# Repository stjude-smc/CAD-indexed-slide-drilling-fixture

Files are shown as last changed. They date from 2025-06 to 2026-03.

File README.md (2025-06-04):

# Indexed Slide Drilling Fixture for Quartz Microfluidic Slides

## Motivation

Drilling precise, evenly spaced holes in quartz slides for microfluidic applications is challenging due to the risk of slide flexing, misalignment, and surface damage. Commercial solutions are limited and often lack the flexibility for custom layouts.

**Benefits of this custom-made indexed slide drilling fixture:**

* Rigid, reproducible slide positioning using three reference protrusions and two spring-loaded plungers
* Indexed gear rack mechanism with external spring-loaded plunger enables accurate, repeatable linear movement between hole positions
* Water-filled slide pocket for cooling and debris reduction during drilling
* Cutout beneath the imaging region prevents scratching of the slide surface
* Parametric CAD design allows rapid adjustment of hole pitch and number of fluidic channels for custom microfluidic layouts
* Can be fabricated quickly from stacked, laser-cut acrylic sheets and standard hardware

## Folder Structure

- **cad/** → CAD models
  - **parts/commercial/** → Purchased parts: 3D models, drawings, datasheets, etc.
  - **asm/** → CAD assemblies

- **bom/** → Bill of materials
  - `bom.xlsx` → List of all parts and materials

- **mfg/** → Manufacturing files
  - **3dp/** → 3D printing models (`.STL`, `.preform`, `.3mf`, `.gcode`, ...)
  - **laser/** → Laser cutting files (`.DXF`, `.SVG`, `.PDF`, `.las`)

- **docs/** → Drawings, datasheets, and assembly guides
  - **dwg/** → Drawings for parts and assemblies (`.PDF`)

- **imgs/** → Images for `README.md`

## Manufacturing

The indexed slide drilling fixture can be fabricated using two alternative methods, depending on available equipment and desired material properties:

### Option A: Laser-Cut Acrylic Assembly

1. **Material:** Acrylic glass sheets (thicknesses: 1/16", 3/32", 7/32", and 1/4")
2. **Equipment:** Universal Laser VLS2.30 (or equivalent laser cutter)
3. **Process:**
   - Use the provided `.PDF` or `.SVG` files (see `mfg/laser/`) to laser cut each layer of the fixture.
   - Align and fuse layers together with dichloromethane for a strong, seamless bond.
   - Install spring-loaded plungers before fusing the top layer.

### Option B: 3D Printed Assembly

1. **Material:** Tough 2000 Resin (Formlabs) or equivalent
2. **Equipment:** Formlabs Form 4 (or equivalent SLA 3D printer)
3. **Process:**
   - Use the provided `.STL` files (see `mfg/3dp/`) to print each fixture component.
   - Post-process printed parts as recommended by the resin manufacturer (wash, cure, etc.).
   - Assemble the fixture by gluing parts together with cyanoacrylate (superglue).
   - Install spring-loaded plungers before fusing the top layer.

**Note:**  
Both manufacturing approaches produce a robust fixture suitable for repeated use. The parametric CAD design can be easily adapted for either method to accommodate different slide formats, hole patterns, or channel pitches.

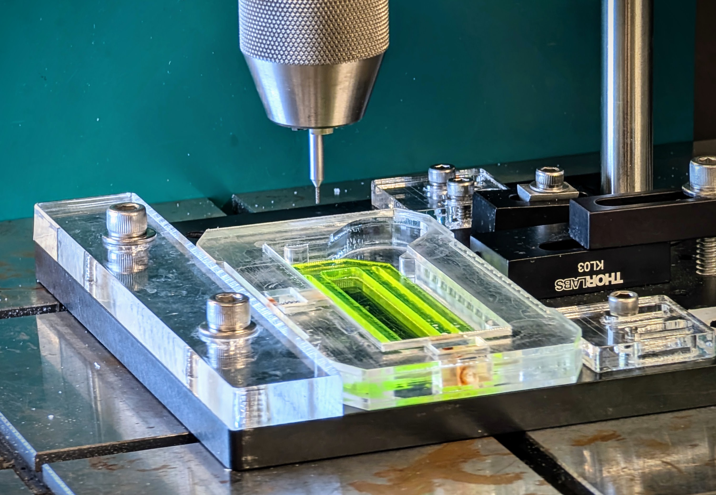
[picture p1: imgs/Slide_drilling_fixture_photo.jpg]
preview


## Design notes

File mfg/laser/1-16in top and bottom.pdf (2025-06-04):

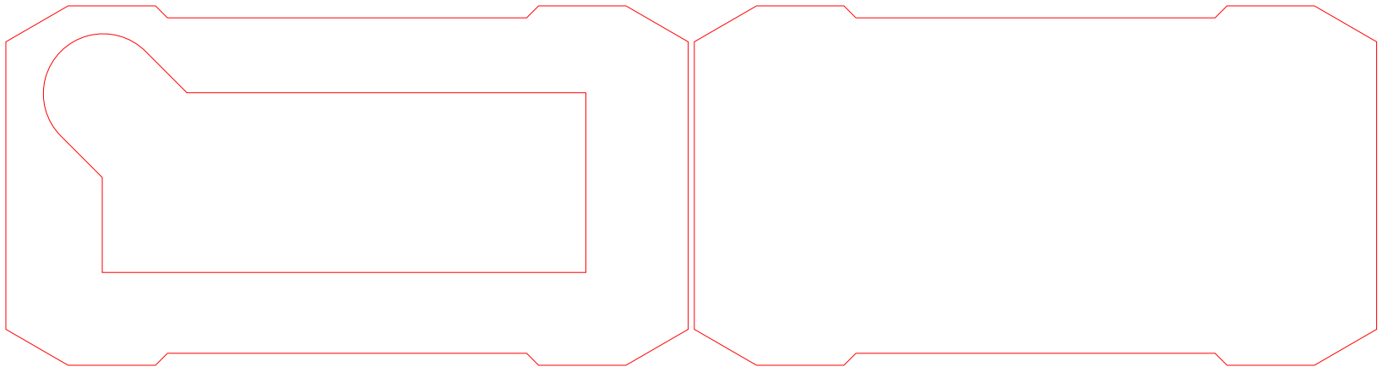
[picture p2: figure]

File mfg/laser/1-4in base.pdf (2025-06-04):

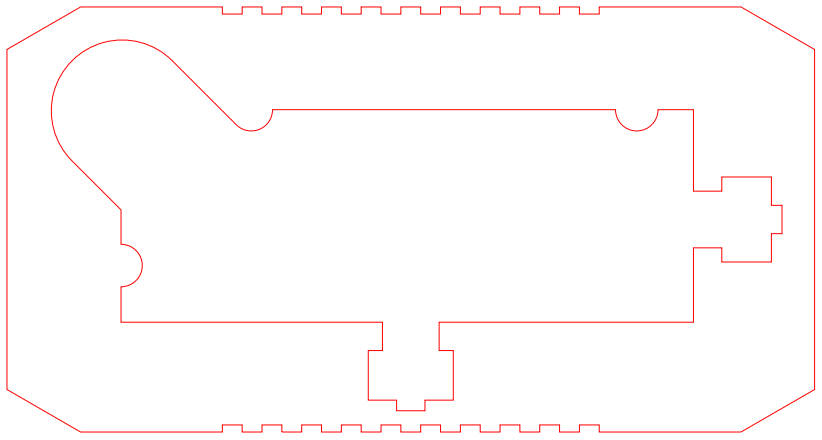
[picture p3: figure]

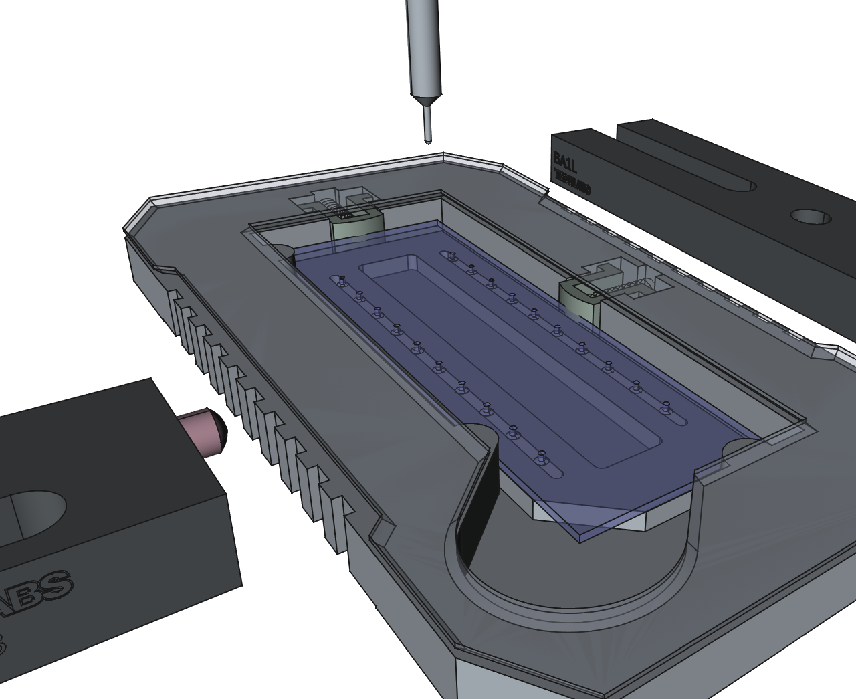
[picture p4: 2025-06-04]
imgs/Slide_drilling_fixture_02.png

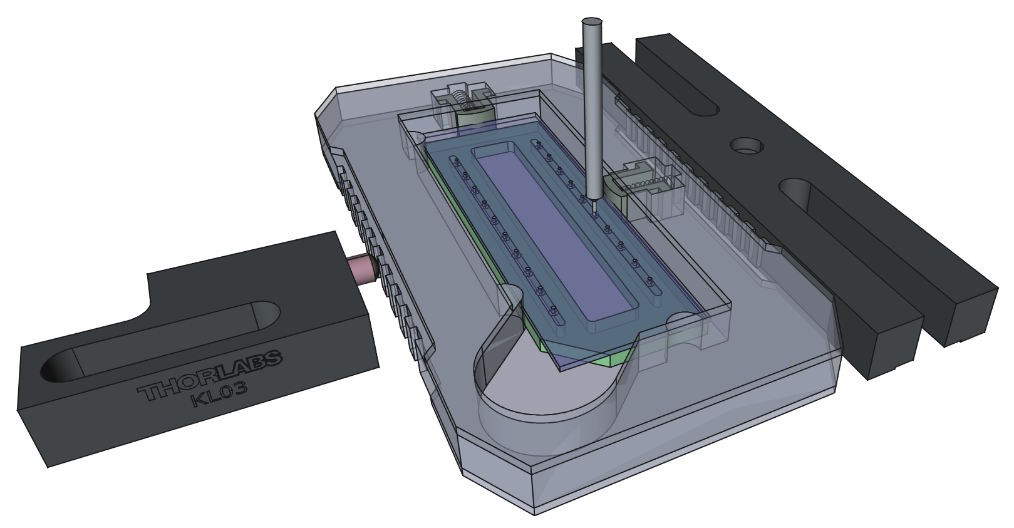
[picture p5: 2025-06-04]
imgs/Slide_drilling_fixture_01.png

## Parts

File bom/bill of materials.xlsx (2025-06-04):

Bill of materials
pTIRF indexed slide drilling fixture v1.0.0
Commercial materials
# | Name | Vendor | Catalog # | Asm qty | Price | Pkg qty | Mult. | Cost | Description
Parts
1 | Compression springs | McMaster | 9435K22 (https://www.mcmaster.com/9435K22/) | 2 | $5.76 | 5 | 0.40 | $2.30 | 302 Stainless Steel Compression Springs 0.75" Long, 0.18" OD, 0.148" ID
2 | Guide | Thorlabs | BA1L (https://www.thorlabs.com/thorproduct.cfm?partnumber=BA1L) | 1 | $14.53 | 1 | 1.00 | $14.53 | BA1L - Mounting Base, 1" x 4.5" x 3/8"
3 | Kinematic positioner | Thorlabs | KL03 (https://www.thorlabs.com/thorproduct.cfm?partnumber=KL03) | 1 | $7.76 | 1 | 1.00 | $7.76 | Spring-Loaded Plunger, 0.85" (21.6 mm) Long Slot
4 | Aluminum breadboard | Thorlabs | MSB6 (https://www.thorlabs.com/thorproduct.cfm?partnumber=MSB6) | 1 | $8.76 | 2 | 0.50 | $4.38 | 6" x 6" x 3/8" Mini-Series Aluminum Breadboard, 8-32 and 1/4"-20 Taps
Raw materials
1 | 1/16" (1.6mm) acrylic glass | McMaster | 8560K178 (https://www.mcmaster.com/8560K178/) | 1 | $3.44 | 1 | 1.00 | $3.44 | 6" x 12" x 1/16" cast acrylic sheet
2 | 3/32" (2.4mm) acrylic glass | McMaster | 8560K188 (https://www.mcmaster.com/8560K188/) | 1 | $3.65 | 1 | 1.00 | $3.65 | 6" x 12" x 3/32" cast acrylic sheet
3 | 7/32" (5.6mm) acrylic glass | McMaster | 8560K179 (https://www.mcmaster.com/8560K179/) | 1 | $9.92 | 1 | 1.00 | $9.92 | 6" x 12" x 7/32" cast acrylic sheet
4 | 1/4" (6.4mm) acrylic glass | McMaster | 8560K359 (https://www.mcmaster.com/8560K359/) | 1 | $13.96 | 1 | 1.00 | $13.96 | 6" x 12" x 1/4" cast acrylic sheet
5 | Tough 2000 resin | Formlabs | RS-C2-TO20-11 (https://formlabs.com/store/materials/tough-2000-resin) | 50 | $149 | 1000 | 0.05 | $7.45 | Tough 2000 Resin (Form 4) 1 L
 |  |  |  |  |  |  | Total | $67.39
Custom parts
# | Name | Qty | Material
Laser cut parts (Universal laser VLS2.30) |  |  |  |  | NOTE
1 | Slide drilling fixture top | 1 | 1/16" acrylic |  | The slide drilling fixture can be either
2 | Slide drilling fixture bottom | 1 | 1/16" acrylic |  | a) laser cut and fused with dichloromethane, or
3 | Slide drilling fixture pedestal | 1 | 3/32" acrylic |  | b) 3D printed and glued with superglue
4 | Slide drilling fixture plunger | 2 | 7/32" acrylic
5 | Slide drilling fixture base | 1 | 1/4" acrylic
3D printed parts (Formlabs Form 4)
1 | Slide drilling fixture base | 1 | Tough 2000 resin
2 | Slide drilling fixture top | 1 | Tough 2000 resin
3 | Slide drilling plunger | 2 | Tough 2000 resin

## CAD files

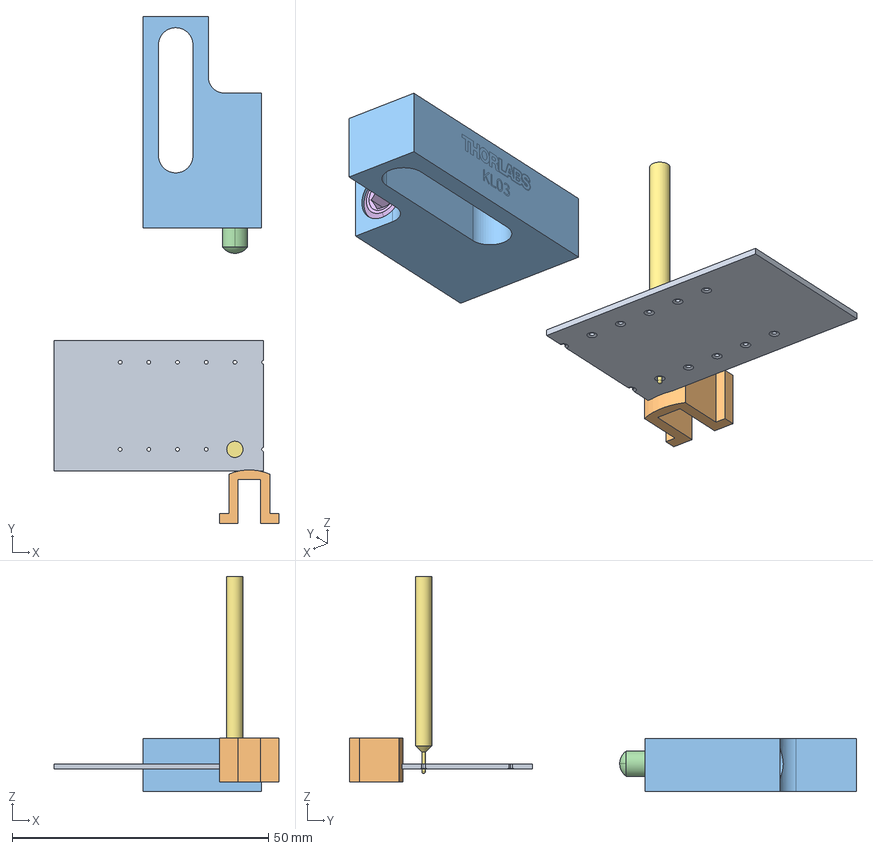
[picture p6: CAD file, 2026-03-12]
cad/asm/indexed slide drilling fixture.FCStd
43.9 x 99.0 x 42.0 mm
QuartzSlide
Plunger
KL03_Step
KL03_Step001
KL03_Step002
KL03_Step003
0.03in Drilling bit

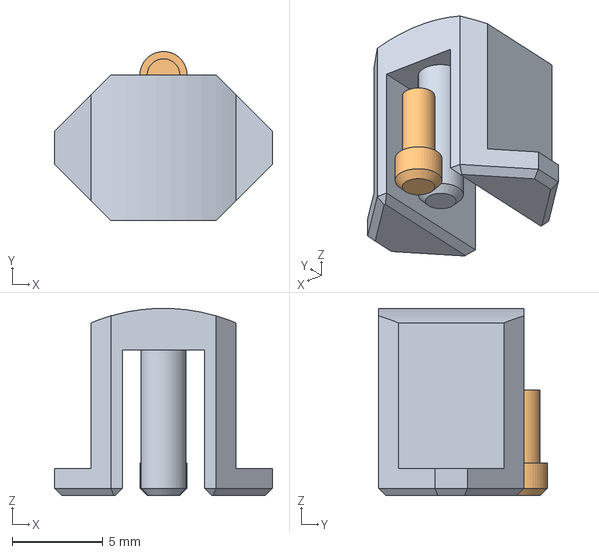
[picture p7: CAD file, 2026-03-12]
cad/parts/alternative plunger.FCStd
12.0 x 9.30 x 10.3 mm
plunger
pin

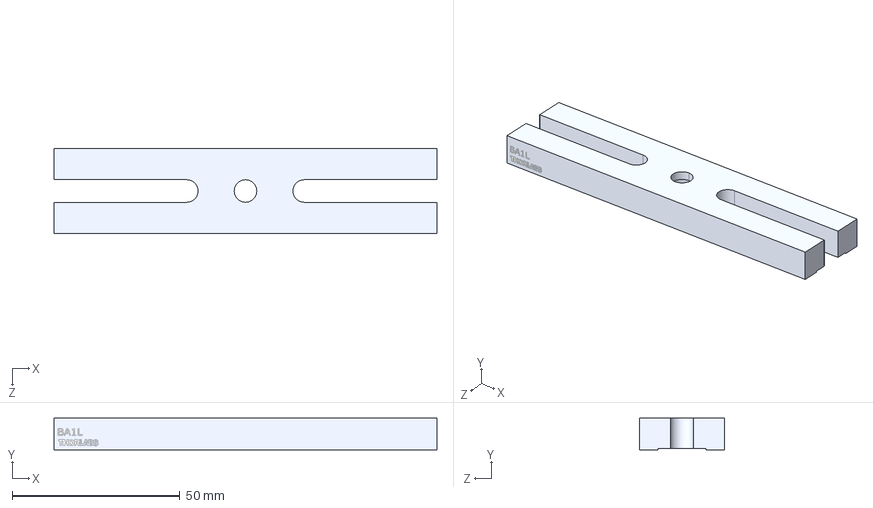
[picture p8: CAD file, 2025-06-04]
cad/parts/commercial/BA1L/BA1L-Step.step
114.3 x 9.53 x 25.4 mm

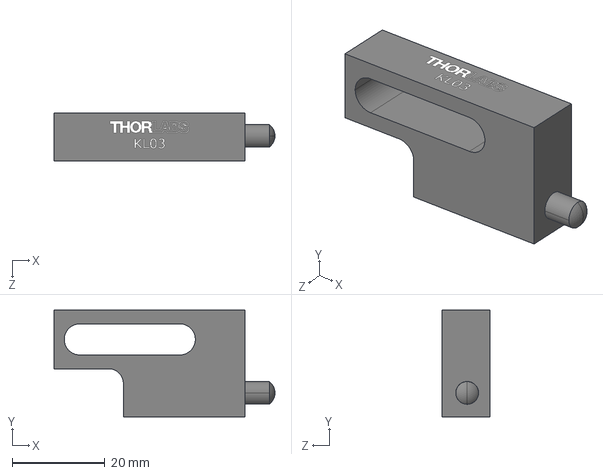
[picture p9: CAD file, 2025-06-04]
cad/parts/commercial/KL03/KL03-Step.step
47.8 x 23.1 x 10.4 mm

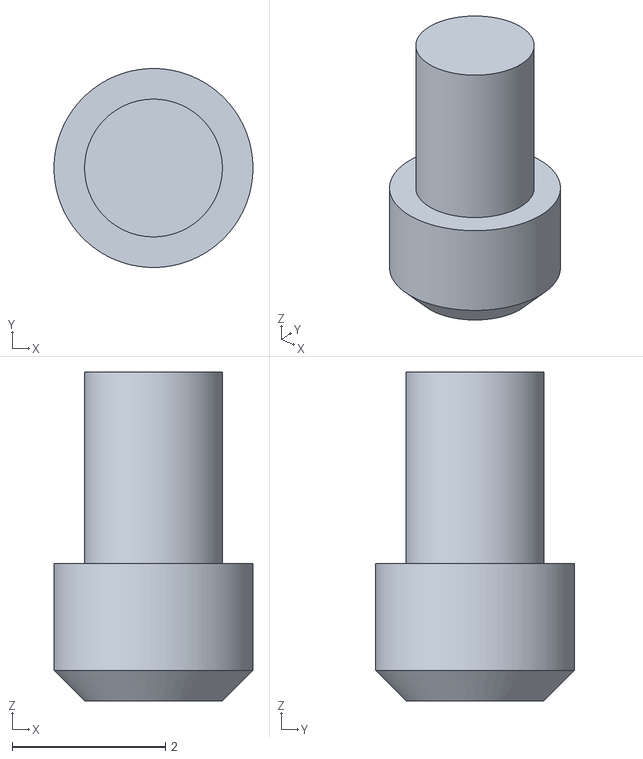
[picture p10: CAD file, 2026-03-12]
mfg/3dp/pin.stl
2.60 x 2.60 x 4.30

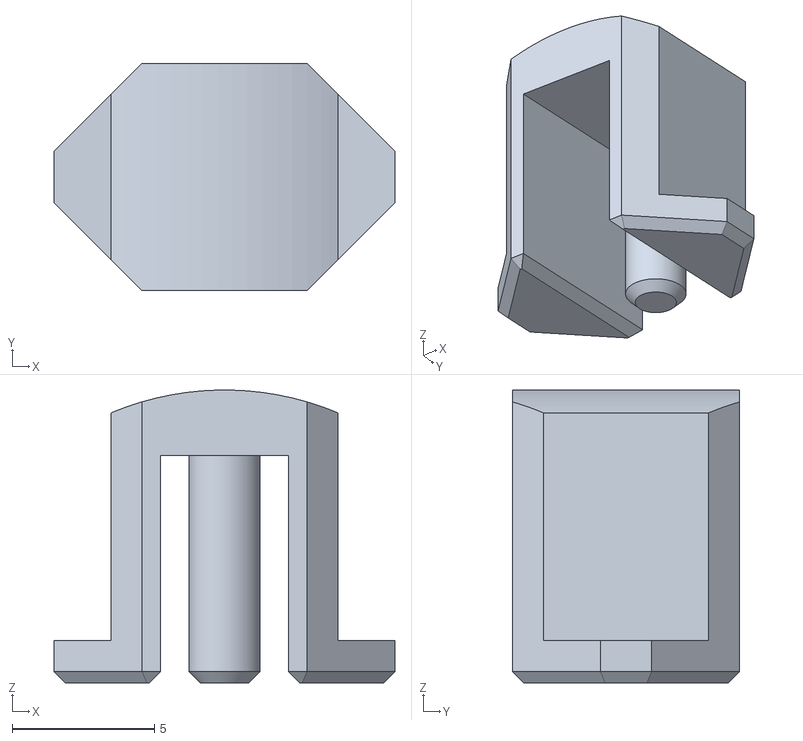
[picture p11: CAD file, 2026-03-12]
mfg/3dp/plunger.stl
12.0 x 8.00 x 10.3

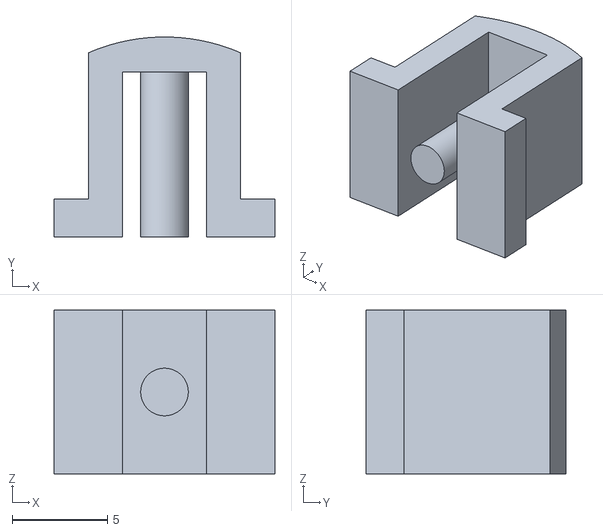
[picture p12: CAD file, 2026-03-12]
mfg/3dp/fixture plunger.stl
11.6 x 10.5 x 8.60

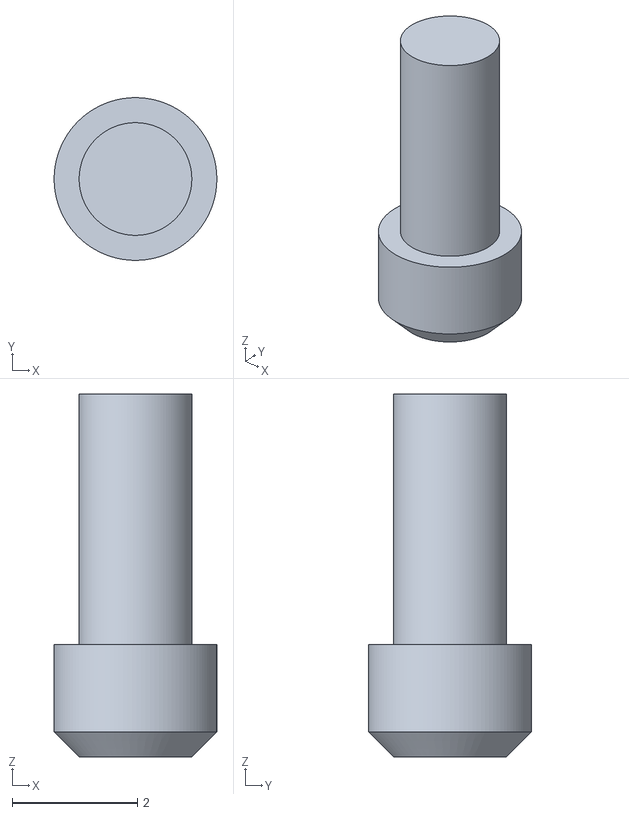
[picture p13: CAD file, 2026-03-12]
mfg/3dp/pin-long.stl
2.60 x 2.60 x 5.80

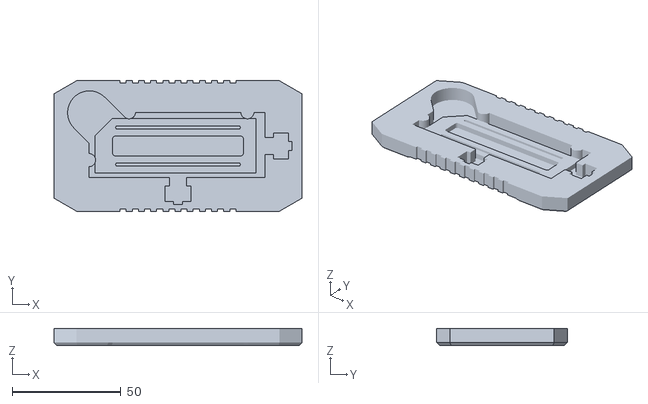
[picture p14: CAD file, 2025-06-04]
mfg/3dp/fixture body.stl
114.0 x 60.0 x 7.85

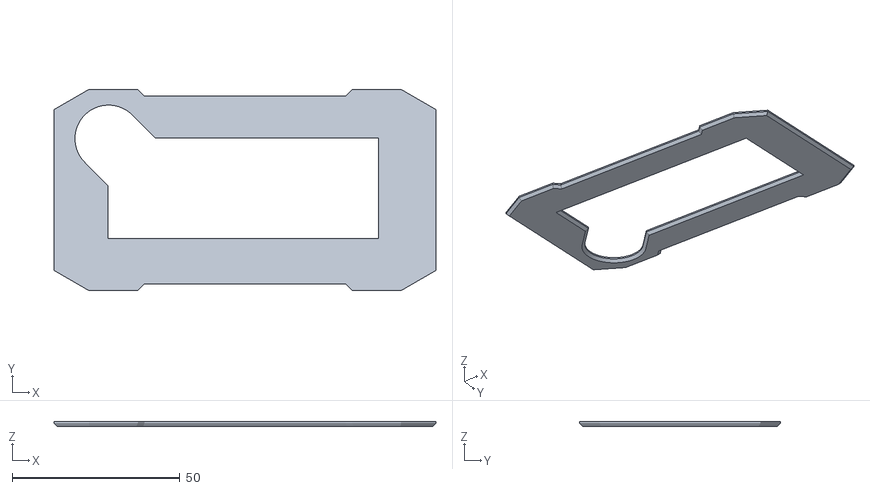
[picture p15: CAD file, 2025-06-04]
mfg/3dp/fixture lid.stl
114.0 x 60.0 x 1.50

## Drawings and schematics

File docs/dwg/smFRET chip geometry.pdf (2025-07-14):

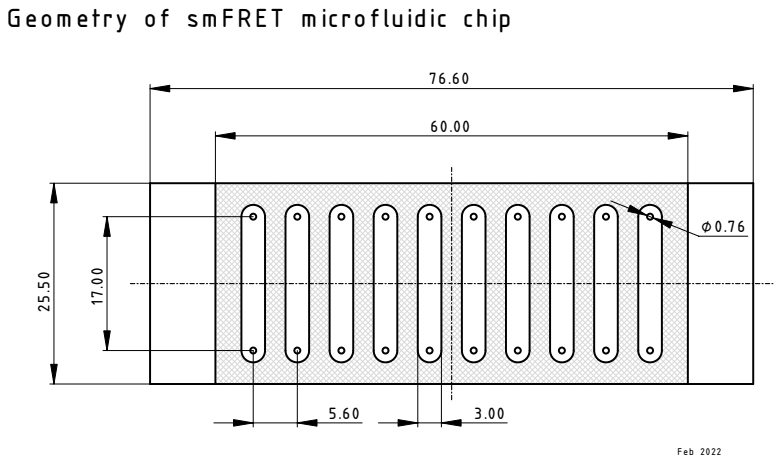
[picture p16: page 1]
Feb 2022

G eom etry of sm FR ET m icrofluidic chip

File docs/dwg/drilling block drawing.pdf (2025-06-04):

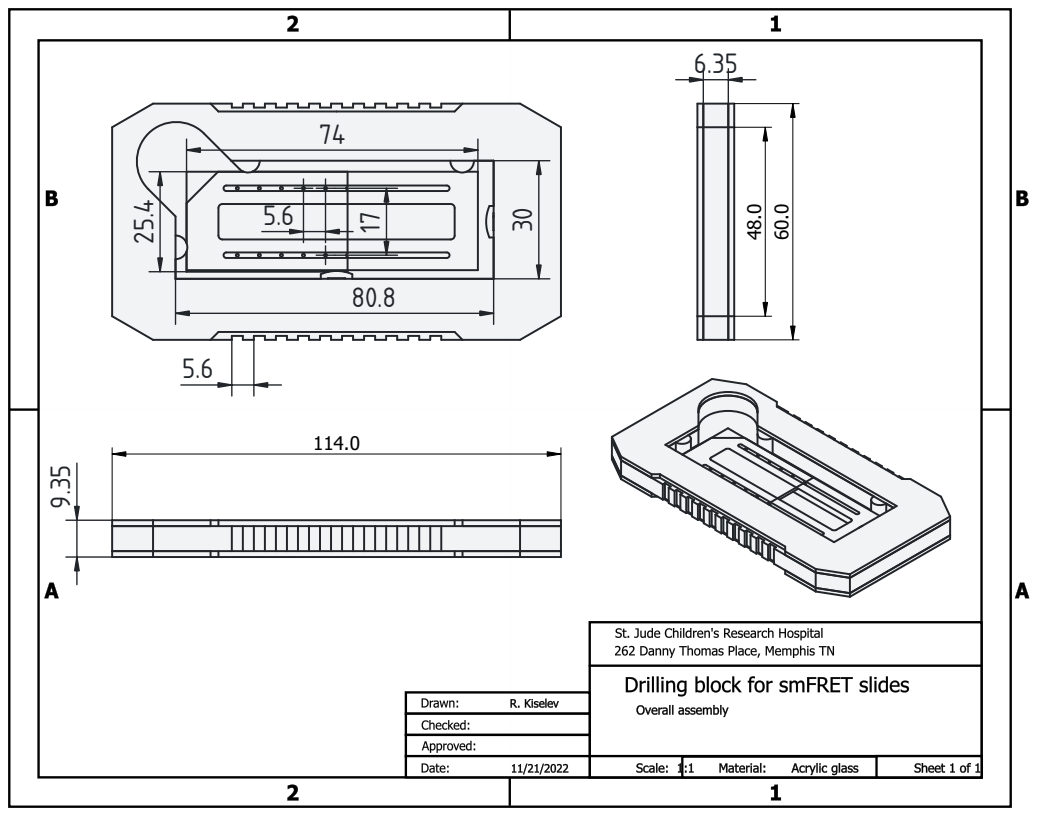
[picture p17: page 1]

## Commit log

2025-06-04 Created github repo of slide drilling fixture based on the CAD template
    [BA1L-Step.step, KL03-Step.step, bill of materials.xlsx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]
2026-03-12 Added alternative design of a plunger (for 3D printing)
    [alternative plunger.FCStd, fixture plunger.stl, indexed slide drilling fixture.FCStd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]
